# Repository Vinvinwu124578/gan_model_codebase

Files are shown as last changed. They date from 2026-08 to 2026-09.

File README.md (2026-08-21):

# TacTip GAN Coverage Board and CR3 Sampler

这个仓库保存用于 TacTip sim-to-real GAN 数据采集的完整硬件与自动采样流程：

- 四块可打印的高凸起几何覆盖板 STL；
- 与 150 mm M6 孔距配合的 TacTip 校准托座；
- Dobot CR3 自动规划、IK 预检、视觉接触检测及触觉图像采集脚本；
- 采样板/托座重新生成与装配预览工具。

仓库中的默认硬件是实际用于 CR3 调试的 **v4 deep-contact 版本**。每块板为
`170 x 170 mm`，四块组装后为 `340 x 340 mm`；每块板的四个 M6 孔中心距为
`150 x 150 mm`，板孔直径为 `6.0 mm`。

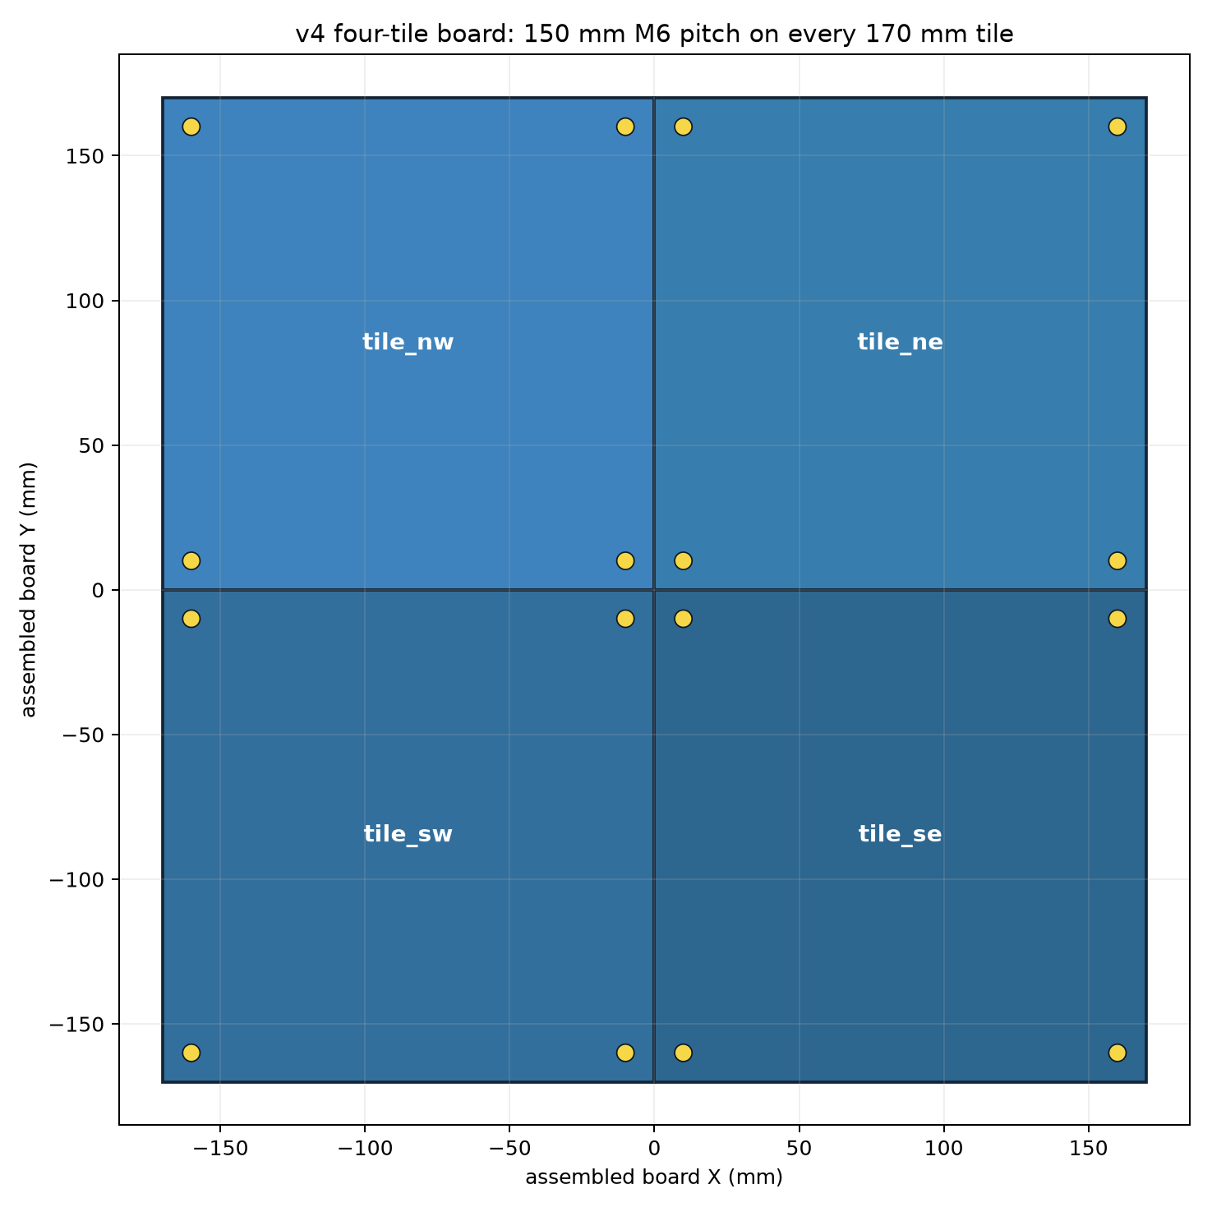
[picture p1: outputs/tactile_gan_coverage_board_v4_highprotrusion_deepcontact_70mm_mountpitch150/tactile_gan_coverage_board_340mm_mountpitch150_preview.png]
Four-tile mounting layout


## Repository layout

```text
tools/
  auto_cr3_v4_150mm_coverage_board_sampler.py   # 推荐入口
  auto_cr3_coverage_board_sampler.py            # 完整规划与采集实现
  preprocess_tactip_markers.py                  # 批量 Hough + 颜色二值化
  tactip_hough_chromatic.py                     # 批处理与在线采样共用算法
  tactip_runtime_preprocess.py                  # 自动采样在线预处理封装
  ...                                           # CR3、相机、预处理与硬件生成依赖

outputs/tactile_gan_coverage_board_v4_highprotrusion_deepcontact_70mm_mountpitch150/
  tactile_gan_coverage_board_340mm_tile_*.stl   # 四块打印板
  tactile_gan_coverage_board_340mm_manifest.json
  tactile_gan_coverage_board_340mm_sampling_sites.csv
  tactile_gan_coverage_board_340mm.urdf
  tactip_calibration_dock_lightweight_v1/       # 默认且经过实机流程使用的托座
  tactip_calibration_dock_verified_pitch_v2/    # 可选 150 mm 封闭孔夹持版

tactile_sim2real/pairing.py                     # 配对计划辅助模块
```

不会提交机器人专用的 fixture profile、Tool(2) TCP 或实物采样运行结果。每台机器、
每次重新安装托座后都必须重新示教。

## Installation

Python 3.10 或更高版本：

```bash
python3 -m venv .venv
source .venv/bin/activate
python -m pip install --upgrade pip
python -m pip install -r requirements.txt
```

macOS 还需要在“系统设置 -> 隐私与安全性 -> 相机”中允许 Terminal/Python 使用相机。
`tkinter` 由 Python 系统安装提供，不在 `requirements.txt` 中。

## TacTip image preprocessing

默认预处理已替换为 Hough 圆边界检测与蓝黄颜色过滤：

1. 灰度梯度只用于 Hough 圆周投票，不寻找最亮像素；
2. 对每个圆内部计算 `2B-G-R` 中位数，保留蓝灰 marker，排除金黄玻璃反光；
3. 使用当前图片实测的圆心和半径生成严格 `0/255` 二值图；
4. 原分辨率与 `256 x 256` 输出都必须保持 331 个独立连通域，否则拒绝该帧；
5. 原始相机照片永远保留，不会被预处理图覆盖。

处理单张图片：

```bash
.venv/bin/python tools/preprocess_tactip_markers.py \
  --input /absolute/path/to/tactip.png \
  --output-dir outputs/preprocessed_test
```

处理文件夹：

```bash
.venv/bin/python tools/preprocess_tactip_markers.py \
  --input /absolute/path/to/raw_images \
  --glob '*.png' \
  --output-dir outputs/preprocessed_batch
```

自动采样器默认启用同一套算法，标准模型输入保存在
`tactip_preprocessed/model_input_256/`。使用 `--no-tactip-preprocess` 可以只保存原图。
当前默认参数以 1280×960 实拍图为基准，圆间距、半径和 ROI padding 会随输入分辨率
自动缩放；颜色阈值保持在原始 8-bit BGR 色域中。

## Print and assemble

1. 打印 `tile_nw`、`tile_ne`、`tile_sw`、`tile_se` 四个 STL，触觉几何朝上。
2. 按 NW/NE、SW/SE 的顺序组装，不能单独旋转某一块。
3. 使用四角 `6.0 mm` M6 孔把每块板固定在同一平面上。
4. 默认托座安装在当前板块的 local `-Y` 边，并共用南侧两个 150 mm 间距的孔。
5. TacTip 刚性外壳落入圆形定位环，软触头朝下，电缆从外侧开槽离开。

默认托座及装配图位于：

```text
outputs/tactile_gan_coverage_board_v4_highprotrusion_deepcontact_70mm_mountpitch150/
  tactip_calibration_dock_lightweight_v1/
```

`verified_pitch_v2` 是更刚性的封闭孔替代版。更换托座版本后必须使用相应的 design
JSON，并重新示教 fixture profile；不能复用旧托座的 TCP。

## Safe workflow

以下命令都要在仓库根目录运行。示例使用 `tile_nw`、CR3 地址
`192.168.31.88`、Tool 2。

### 1. Teach the seated dock pose

先手动把 TacTip 完全落入托座，再执行：

```bash
.venv/bin/python tools/auto_cr3_v4_150mm_coverage_board_sampler.py \
  --tile tile_nw \
  --teach-dock-from-current \
  --robot-ip 192.168.31.88 \
  --tool 2
```

此步骤只读取当前位置，不发送运动指令。

### 2. Generate a 2,000-sample plan without moving CR3

```bash
.venv/bin/python tools/auto_cr3_v4_150mm_coverage_board_sampler.py \
  --tile tile_nw \
  --samples-per-tile 2000 \
  --dense-spatial-layout region_grid \
  --dense-region-anchor-count 25 \
  --min-post-contact-depth-mm 1 \
  --max-post-contact-depth-mm 10 \
  --output-dir outputs/plans/tile_nw_2000
```

输出包括 CSV、JSON 和可旋转 HTML 规划预览，不连接相机，也不移动机械臂。

### 3. Controller IK preflight without motion

机械臂已上电且 TacTip 仍在示教托座位置时：

```bash
.venv/bin/python tools/auto_cr3_v4_150mm_coverage_board_sampler.py \
  --tile tile_nw \
  --samples-per-tile 2000 \
  --dense-spatial-layout region_grid \
  --dense-region-anchor-count 25 \
  --min-post-contact-depth-mm 1 \
  --max-post-contact-depth-mm 10 \
  --ik-preflight-only \
  --robot-ip 192.168.31.88 \
  --tool 2
```

采样器会检查 `site_high`、approach、contact、最深压入及 retreat，并用候选点替换
不可达点；该模式不会发送 MovL。

### 4. Real collection

先只使用 `--max-samples 1 --first-contact-test` 做有人看护的 1 mm 首次接触测试。
确认坐标、方向、接触检测和回程都正确后，才运行完整批次：

```bash
.venv/bin/python tools/auto_cr3_v4_150mm_coverage_board_sampler.py \
  --tile tile_nw \
  --samples-per-tile 2000 \
  --dense-spatial-layout region_grid \
  --dense-region-anchor-count 25 \
  --min-post-contact-depth-mm 1 \
  --max-post-contact-depth-mm 10 \
  --camera-source 0 \
  --robot-ip 192.168.31.88 \
  --tool 2 \
  --speed 3 \
  --allow-depth-above-csv-limit \
  --return-to-dock \
  --execute \
  --yes-i-confirm-cr3-is-safe
```

`--allow-depth-above-csv-limit` 只能在已经物理验证板材、固定方式与 TacTip 能承受
1-10 mm 协议后使用。

## Safety

- 未同时提供 `--execute` 和 `--yes-i-confirm-cr3-is-safe` 时，脚本不会发送运动。
- 新装夹必须先生成预览，再执行 IK preflight，最后进行单点低压入测试。
- 自动 IK 只能检查运动学可达性，不能替代完整机械臂、线缆、夹具和环境碰撞检查。
- 接触失败默认安全回到高位并停止批次；不要在不检查机器人状态时盲目续跑。
- 急停、保护空间、速度限制和现场看护仍由操作者负责。

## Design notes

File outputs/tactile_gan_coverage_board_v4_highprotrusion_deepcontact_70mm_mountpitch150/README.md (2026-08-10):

# v4 70 mm Coverage Board: 150 mm M6 Pitch

This is a non-destructive mounting-hole variant of the original v4 deep-contact board. Each of the four 170 x 170 mm tiles keeps the same tactile geometry, STL-local frame, URDF frame and sampling CSV as v4. Only its four M6 clearance holes changed.

## Hole pattern

Every tile uses local hole centres `(-75,-75)`, `(-75,75)`, `(75,-75)`, `(75,75)` mm. The horizontal and vertical centre-to-centre pitch is therefore exactly `150 mm`. The nominal M6 hole diameter is `6.0 mm`.

The calibration dock for this variant attaches to one edge pair at local Y = -75 mm.

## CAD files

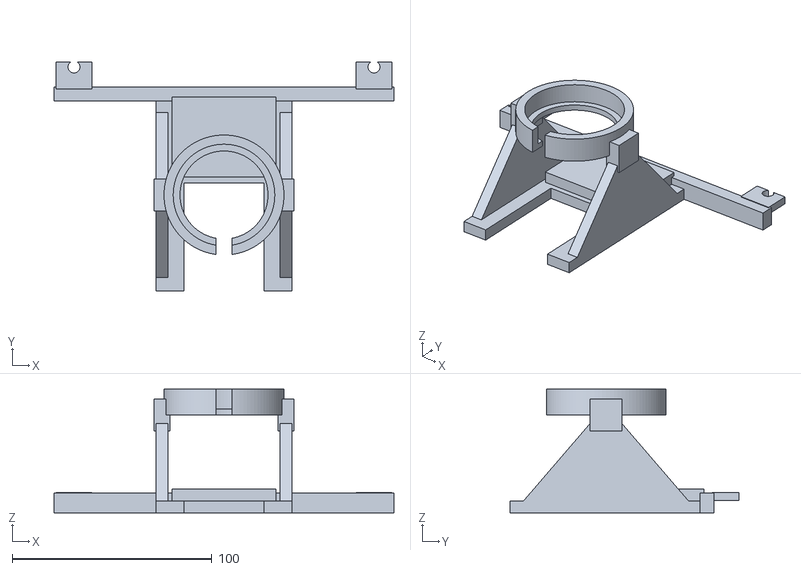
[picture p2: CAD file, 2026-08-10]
outputs/tactile_gan_coverage_board_v4_highprotrusion_deepcontact_70mm_mountpitch150/tactip_calibration_dock_lightweight_v1/v4_150mm_tactip_calibration_dock_lightweight.stl
170.0 x 114.5 x 62.0

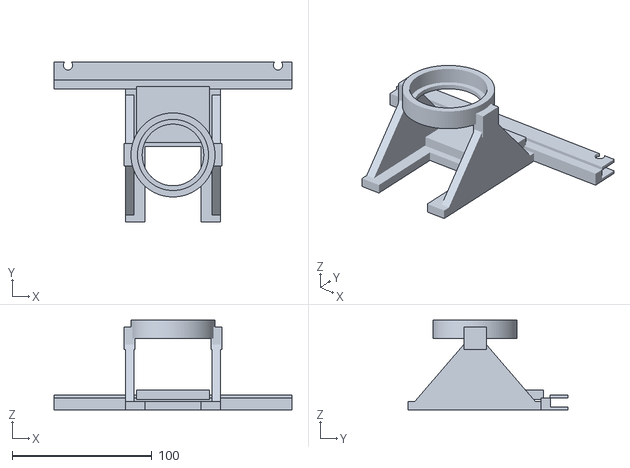
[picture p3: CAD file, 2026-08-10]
outputs/tactile_gan_coverage_board_v4_highprotrusion_deepcontact_70mm_mountpitch150/tactip_calibration_dock_verified_pitch_v2/v4_tactip_calibration_dock_v2_exact_150.stl
170.0 x 114.5 x 64.0

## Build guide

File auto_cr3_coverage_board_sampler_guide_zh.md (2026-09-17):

# `auto_cr3_coverage_board_sampler.py` 详细说明

> 源文件：`tools/auto_cr3_coverage_board_sampler.py`<br>
> 适用版本：2026-09-16 当前工作区版本（约 5,271 行）<br>
> 目标读者：需要理解、运行、调试或继续开发 CR3 + TacTip 覆盖板自动采样流程的研究人员

## 1. 这个脚本解决什么问题

这个脚本是四块 GAN 触觉覆盖板的真实机械臂采样入口。它把下面几件本来相互独立的事情串成一个受约束的流程：

1. 从固定 TacTip 托座建立真实 CR3 坐标系与板子 CAD 坐标系之间的刚体关系。
2. 根据板子 manifest、采样点 CSV 和解析几何生成触觉采样计划。
3. 把每个板上采样点换算成 CR3 基座坐标系中的 TCP 位姿。
4. 在运动前检查起始托座状态、Tool/User、IK、运动反馈和深度上限。
5. 在每个点建立新的无接触图像基线，再用 marker 光流寻找真实接触。
6. 从视觉接触点继续压入指定深度并保存原图、预处理图、TCP 和统计量。
7. 处理无接触、断点续采、整批 IK 筛选、回托以及受限恢复。
8. 输出可复核的 CSV、JSON、HTML 轨迹和图像报告。

它不是单纯的“读 CSV 后逐点 `MovL`”脚本。它同时承担了坐标配准器、采样规划器、视觉接触检测器、机器人安全门、数据记录器和恢复工具的职责。

## 2. 最重要的设计原则

### 2.1 托座是机械配准基准

脚本不在每次运行时重新拟合任意三维点。TacTip 放入具有机械键位的固定托座后，保存的 Tool(2) TCP 和托座设计文件共同确定板子坐标系。

对于带横档的托座，还会保存 TacTip 接触横档时的触觉图像。正式运行必须同时满足：

- 当前 Tool(2) TCP 与保存的托座 TCP 相符；
- 当前触觉图像与保存的横档接触图像相符。

因此，“TCP 在附近但 TacTip 没真正落到底”不会被当成有效归位。

### 2.2 CAD 高度只负责给出名义位置

模型提供每个点的名义表面高度，但最终是否接触由实时触觉图像决定。实际流程是：

```text
CAD 名义表面
    -> 从上方逐步接近
    -> marker 位移达到动态阈值
    -> 得到视觉接触点
    -> 再压入该样本要求的 1-10 mm
```

这样可以吸收打印误差、装配高度误差和局部曲面高度差，但搜索仍受硬深度上限约束。

### 2.3 每个真实 `MovL` 前都做即时 IK

默认不会在 2,000 点运行前等待整批 IK 扫描，但 `move_and_verify()` 会在每个真实 `MovL` 前读取当前关节角，并用相同 near-joint 分支调用控制器 `InverseSolution`。没有解时不会发送该次 `MovL`。

`--preflight-all-routes` 是额外的整批筛选，不是即时 IK 的替代品。

### 2.4 失败时不猜测机器人位置

如果 `GetPose`/`GetAngle` 反馈无效、运动误差超限或异常发生在未知阶段，脚本记录错误并停止，不会擅自发送恢复动作。只有起点落在明确限定的几何包络中时，专用恢复模式才允许移动。

## 3. 总体架构

```mermaid
flowchart TD
    A[parse_args 参数解析与静态安全校验] --> B[load_dock_design / load_board_data]
    B --> C{运行模式}
    C -->|托座教学| D[teach_dock_profile / teach_rest_stop_height_profile]
    C -->|仅相机| E[run_capture_camera_only]
    C -->|恢复| F[run_reseat_dock / run_recover_*]
    C -->|计划或采集| G[filter_tile_rows]
    G --> H[build_samples / build_dense_samples]
    H --> I[fixture_from_profile]
    I --> J[make_route]
    J --> K[写 CSV/JSON/HTML 预览]
    K --> L{execute?}
    L -->|否| M[离线计划结束]
    L -->|是| N[run_collection]
    N --> O[检查托座 TCP 与横档触觉图]
    O --> P[可选整批 IK 筛选]
    P --> Q[移动至 site approach]
    Q --> R[search_visual_contact]
    R --> S[最终压入并拍摄]
    S --> T[抬升到 site-high]
    T --> U{还有样本?}
    U -->|是| Q
    U -->|否| V[回托或停在最后 site-high]
    V --> W[collection.json / samples.csv / HTML 报告]
```

## 4. 外部模块边界

主脚本负责组织流程，但以下能力来自同仓库其他模块：

| 模块 | 主脚本使用的能力 |
|---|---|
| `auto_cr3_gelsight_pair_sampler.py` | `GelSightCapture`：打开相机、后台读取带时间戳的新帧 |
| `auto_cr3_visual_contact_search.py` | 多帧中值拍摄、marker 光流统计、位姿误差、`move_and_verify()`、动态图像阈值 |
| `design_tactile_gan_coverage_board_modular.py` | 根据区域 profile、stimulus 和局部 X/Y 解析计算曲面 Z 高度 |
| `live_cr3_gelsight_sampler.py` | `DobotCR3LiveClient`、相机 source 解析、CR3 TCP/IP 命令 |
| `runtime_board_height_datum.py` | 运行时板高基准的绑定、质量检查、生成与加载 |
| `tactip_runtime_preprocess.py` | 331-pin Hough/色彩筛选、原分辨率 marker 图、256x256 模型输入 |

需要特别区分：本文件决定“什么时候拍、什么时候移动、拍完如何判断”；marker 的具体检测和 LK 光流计算在外部模块中实现。

## 5. 输入文件

### 5.1 板子目录 `--board-dir`

目录中必须恰好有一个 `*_manifest.json`。manifest 至少需要描述：

- 四块 tile 的 `tile_id`、中心坐标和 STL；
- 每块 tile 包含哪些 `region_id`；
- 采样 CSV 的相对路径；
- `height_profile`；
- 区域中心、TacTip 名义直径和安全特征区尺寸。

采样 CSV 至少被脚本使用的列包括：

- `site_id`、`region_id`、`category`、`stimulus`；
- `board_x_mm`、`board_y_mm`、`expected_surface_z_mm`；
- `sampling_jitter_radius_mm`；
- `recommended_depth_min_mm`、`recommended_depth_max_mm`。

### 5.2 托座设计 `--dock-design`

JSON 必须属于支持的 schema，并包含：

- `tactip_reference.nominal_seated_tool_tcp_local_mm`；
- 对应的 `tool` 编号；
- 可选 `rest_pose_stop`：横档接触中心和顶面高度；
- 可选 `reference_pad`；
- 可选 STL 路径，仅用于预览。

`geometry_preview_only` 文件可以做离线可视化，但不能授权教学、标高或真实运动。

### 5.3 实物配准 profile `--fixture-profile`

由本脚本教学模式生成，包含：

- 保存的真实 `dock_tcp`；
- Tool、User、tile；
- 托座设计文件 SHA-256；
- 固定 `board_yaw_deg`；
- 横档高度标定和触觉参考图（v3 profile）。

加载时会核对 tile、Tool、User 和托座设计哈希，避免把另一次装夹的 profile 误用于当前实物。

## 6. 坐标系与数学关系

### 6.1 三个核心坐标系

| 坐标系 | 含义 |
|---|---|
| tile local | 板子 CAD 坐标；采样点、区域中心和安全高度都在这里定义 |
| CR3 base | 机器人 `GetPose`/`MovL` 使用的基座坐标 |
| Tool local | Tool(2) 的末端坐标；Tool `+Z` 被定义为真实压入方向 |

保存 profile 时采用以下方向约定：

```text
tile +X = 托座位姿下 Tool +X
tile +Y = 托座位姿下 Tool -Y
tile +Z = 托座位姿下 Tool -Z（物理向上）
Tool +Z = 物理压入方向（向板面）
```

### 6.2 `FixtureTransform` 的变换

固定轴适配矩阵为：

```text
A = diag(1, -1, -1)
```

如果保存的托座旋转矩阵是 `R_dock`，固定板面偏航角是 `R_yaw`，则：

```text
R_tile_to_base = R_dock * A * R_yaw
```

tile-local 点 `p_local` 转为 CR3 base 点：

```text
p_base = p_dock_base + R_tile_to_base * (p_local - p_dock_local)
```

反变换由 `base_to_tile_local()` 完成：

```text
p_local = p_dock_local + R_tile_to_base^T * (p_base - p_dock_base)
```

### 6.3 倾角与压入轴

`tilt_x_deg` 和 `tilt_y_deg` 分别绕已经映射到 base 坐标中的 tile X、Y 轴旋转。最终方向为：

```text
R = R_tilt_y * R_tilt_x * R_dock
press_axis_base = R * [0, 0, 1]^T
```

因此压入不是简单修改 CR3 的 Z 值，而是沿当前 Tool `+Z` 在 base 坐标中的单位向量运动。倾斜采样时 X、Y、Z 都可能同时变化。

### 6.4 Euler 角的数值连续性

同一个旋转可以写成 `+178°` 或 `-182°`。`FixtureTransform.pose()` 会把新 Euler 角包裹到靠近托座保存角度的等价值，便于检查计划，也减少控制器看到不必要的 360° 数值跳变。

## 7. 核心数据结构

### 7.1 `FixtureTransform`

冻结 dataclass，保存一次装夹的刚体映射。

| 字段/方法 | 作用 |
|---|---|
| `dock_tcp` | 实测托座 Tool TCP，6 维 |
| `dock_tcp_local_mm` | 同一基准在 CAD/tile local 中的 3D 坐标 |
| `tile_to_base` | tile local 到 CR3 base 的 3x3 旋转矩阵 |
| `dock_rotation` | 托座 TCP 本身的旋转矩阵 |
| `board_yaw_deg` | 装夹中固定的板面偏航角 |
| `position()` | 只变换位置 |
| `orientation()` | 生成带 X/Y 倾角的末端旋转 |
| `pose()` | 生成完整 X/Y/Z/Rx/Ry/Rz |
| `press_axis()` | 得到 base 坐标中的真实压入轴 |
| `local_vector()` | 把 base 中的位移向量旋回 tile local |

### 7.2 `BoardSample`

每个计划样本的不可变记录。关键字段分为四组：

| 组 | 字段 |
|---|---|
| 身份 | `index`、`sample_id`、`tile_id`、`source_seed_site_id`、`region_id` |
| 物理类别 | `category`、`stimulus`、`replicate` |
| 接触位置 | `local_contact_mm`、`expected_surface_z_mm`、`jitter_x_mm`、`jitter_y_mm` |
| 接触条件 | `post_contact_depth_mm`、`tilt_x_deg`、`tilt_y_deg` |

`local_contact_mm` 是 tile 中的名义零接触点；`post_contact_depth_mm` 是视觉找到真实接触后继续压入的量，两者不能混为一谈。

## 8. 运行模式与分派顺序

`run()` 按以下优先级分派。前面的模式命中后不会继续执行后面的普通采样逻辑。

| 顺序 | 模式 | 是否连接 CR3 | 是否运动 |
|---:|---|---:|---:|
| 1 | `--capture-camera-only` | 否 | 否 |
| 2 | `--calibrate-height-from-rest-stop` | 是 | 否 |
| 3 | `--teach-dock-from-current` | 是 | 否 |
| 4 | `--recover-low-pose-to-dock` | 是 | 取决于 `--execute` |
| 5 | `--calibrate-runtime-height` | 是 | 是 |
| 6 | 普通规划、预览、预检或采集 | 视后续参数而定 | 视后续参数而定 |

普通规划完成后又按以下优先级执行：

1. `--reseat-dock-only`
2. `--recover-reference-to-dock`
3. `--verify-dock-tactile-reference-only`
4. `--ik-preflight-only`
5. 没有 `--execute`：仅输出计划
6. 有 `--execute`：进入 `run_collection()`

## 9. 一次正式采集的完整时序

### 9.1 离线阶段

1. 解析参数并拒绝不兼容组合。
2. 加载托座设计、板子 manifest 和采样 CSV。
3. 按 tile、region、site 筛选 CSV。
4. 生成普通或精确数量的 dense 样本。
5. 应用零倾角、首点测试、断点续采等变换。
6. 加载 fixture profile，并检查哈希与 Tool/User。
7. 生成每个样本的名义 contact、approach、site-high 和最深允许点。
8. 写出计划 CSV/JSON 和交互式 HTML；此阶段不会连接机械臂。

### 9.2 连接设备后的起始安全门

1. 打开相机并创建预处理器。
2. 连接 CR3，设置 User/Tool，要求机器人可运动且空闲。
3. 读取当前关节和 TCP。
4. `dock_alignment_decision()` 把状态分为：
   - `already_seated`：在托座容差内；
   - `aligned_above_dock`：XY/姿态几乎完全对齐，只在托座上方 0.1-5 mm；
   - `unsafe_start_pose`：其余状态。
5. 第二种状态默认允许以不高于 1% 的速度纯竖直回落到保存 TCP；第三种状态拒绝移动。
6. 对有横档的托座，再拍一张实时触觉图，与保存参考比较 marker 位移、纹理相关性和归一化 MAE。

### 9.3 离开托座与整批 IK 策略

默认不接触额外 reference pad，而是：

```text
seated dock -> dock_exit
```

然后确认实际 TCP 已到 `dock_exit`。如果启用 `--preflight-all-routes`，此时检查候选池并用可达备用点替换不可达点；默认则保留原计划，只在每次真实运动前做即时 IK。

### 9.4 单样本运动与接触

普通非连续模式的进场路线：

```text
dock_exit -> dock_high -> site_high -> approach
```

连续模式除首点外的进场路线：

```text
previous site_high -> next site_high -> approach
```

到 approach 后：

1. 拍无接触 baseline。
2. 原地拍多组 noise probe，计算当前点自己的阈值。
3. 沿 `press_axis_base` 每次最多移动 0.5 mm。
4. 每步拍新图并计算 marker 位移 mean 和 P95。
5. 两项均超过阈值才算 hit。
6. 在同一 TCP 再拍，达到 `consecutive_hits` 才确认接触。
7. 沿同一压入轴继续移动 `post_contact_depth_mm`。
8. 拍最终 capture，保存图像与实际 TCP。
9. 抬升回 site-high。

### 9.5 批次结束

默认通过 dock-high、dock-exit 回到保存的托座 TCP。也可以用 `--leave-at-site-high` 留在最后一个 site-high，但这只适合诊断。

## 10. 样本规划模块

### 10.1 CSV 筛选

`filter_tile_rows()` 先按当前 tile 的 `region_ids` 过滤，再应用可重复的 `--region` 和 `--site`。不存在的 region/site 立即报错，不会静默忽略。

### 10.2 quick / standard / dense profile

没有 `--samples-per-tile` 时使用 profile：

| profile | seed 选择 | 每个 seed 重复数 |
|---|---|---:|
| `quick` | 只取编号 1、5、9 | 1 |
| `standard` | 全部 | 2 |
| `dense` | 全部 | 4 |

倾角从 `TILTS_BY_CATEGORY` 中按类别轮换。flat/curvature/multi-touch 最大约 3°，edge X 方向可到 4°，small-feature 最大约 2°。

### 10.3 精确数量 dense 计划

提供 `--samples-per-tile N` 后，`build_dense_samples()` 保证最终恰好生成 N 个样本：

1. 在选择到的 region 间尽量平均分配数量。
2. 默认 `region_grid` 在每个区域建立正方形锚点阵列。
3. 锚点窗口会扣除 TacTip 半径，避免圆形触头跨入相邻单元。
4. 每个格点加入不超过单元尺寸 10% 的确定性低差异扰动。
5. 用互质 stride 遍历锚点，先覆盖全部位置再重复。
6. 每个实际 X/Y 绑定最近的 CSV seed，用它的类别、stimulus 和安全压深区间。
7. 用解析曲面函数重新计算该 X/Y 的表面 Z，而不是复制最近 seed 的 Z。
8. 压深和倾角都由带 seed 的低差异序列产生，因此可复现。

如果明确指定 `--site`，默认的 `region_grid` 会自动变成围绕该 seed 的 `seed_jitter`，用于局部重复实验。

### 10.4 压深分布

默认全局要求是 1-10 mm，但 `--respect-csv-depth-limits` 默认开启。每个样本实际允许范围为：

```text
lower = max(全局最小值, CSV 推荐最小值)
upper = min(全局最大值, CSV 推荐最大值)
```

没有交集会在规划阶段报错。区间内使用 base-5 低差异序列，而非普通伪随机数。

使用 `--ignore-csv-depth-limits` 时，真实执行如果存在超出 CSV 上限的样本，还必须显式增加 `--allow-depth-above-csv-limit`。

### 10.5 IK 备用候选池

只在整批 IK 预检时需要。候选数为：

```text
ceil(请求样本数 * ik_candidate_multiplier)
```

默认倍数是 2。备用点继续同一确定性 dense 序列，因此替换不可达点时不会跳出已知安全区域，也不会破坏每个 region 的目标数量。

## 11. 路线规划模块

### 11.1 `make_route()` 生成的关键位姿

| 位姿 | 含义 |
|---|---|
| `contact_tcp` | CAD/高度校正后的名义零接触位姿 |
| `approach_tcp` | 沿压入轴反方向退 `approach_clearance_mm` |
| `site_high_tcp` | 相同 X/Y、配置的 tile-local 安全高度 |
| `dock_exit` | 从托座基准沿 tile +Z 纯竖直抬升 |
| `dock_high` | 托座 X/Y 上方的公共安全高度 |

板高 correction 只作用于板面 contact/approach；托座和公共安全高度不跟着改变。对 site-high 的 correction 还会去掉任何会降低安全面的法向分量。

### 11.2 最深允许 TCP

对样本压深 `d` 和接触搜索余量 `m`：

```text
maximum_below_nominal = min(全局硬上限, d + m)
```

视觉找接触本身最多走到：

```text
max_contact_depth_from_approach
    = approach_clearance + maximum_below_nominal - d
```

找到接触后再压入 `d`。因此最终 capture 不会深于名义面下 `maximum_below_nominal`。这里特意为最终压入预留了空间，不能把“接触搜索距离”和“压入深度”直接相加两次。

### 11.3 连续采样模式

`--continuous-board-transit` 不会在每个点后回托：

```text
contact -> current site_high -> next site_high -> next approach
```

所有横向运动仍在共同的 `safe_height_mm` 完成。它显著提高效率，但不会取消每次 `MovL` 的即时 IK 和反馈检查。

## 12. 视觉接触检测模块

### 12.1 图像输入

默认相机设置为 1280x960、30 fps。每次“拍一张”不是取单帧，而是读取若干质量合格的新帧后做逐像素中值，降低闪烁和偶发模糊。

严格预处理要求每张被接受图像独立检测到配置数量的 marker（默认 331）。检测失败时只重拍新图，不会从上一张图补点。

### 12.2 每个采样点都有独立 baseline

`prepare_site_baseline()` 在 approach 位姿执行：

1. 用 `baseline_frames` 拍 baseline。
2. 原地再拍 `noise_probes` 组图。
3. 每组都与 baseline 计算去除整体相机运动后的局部 marker 位移。
4. 分别得到 mean 和 P95 的噪声序列。

动态阈值公式为：

```text
threshold = max(
    人工下限,
    noise_median + noise_multiplier * max(1.4826 * MAD, 0.05)
)
```

默认人工下限：mean 0.10 px，P95 0.45 px。

### 12.3 命中规则

某一步只有同时满足以下条件才是 contact evidence：

```text
marker_motion.mean >= threshold.mean
AND
marker_motion.p95 >= threshold.p95
```

之后保持同一位姿再次拍摄。默认至少连续命中两次；高度测量和运行时标高会强制至少三次。

### 12.4 为什么在同一位姿确认

确认帧不会继续向下移动。这样首个命中 TCP 仍对应同一个机械位置，也不会因为“为了确认又压了一步”而消耗最后的深度预算。

### 12.5 高度测量的 bracket refinement

普通数据采集只需要稳定找到接触。`--height-measurement` 还要估计接触阈值所在的窄区间：

1. 先记录最后一个 no-contact TCP 和第一个 contact TCP。
2. 回到 no-contact 端确认已经释放。
3. 在已探索区间内按最多 0.02 mm 步长重新前进。
4. 只接受宽度不超过 0.04 mm 的正 bracket。

它测量的是“图像检测阈值接触”，不是力传感器定义的严格零力接触。

运行时全板高度标定故意使用已经稳定确认的 0.5 mm 粗 bracket，不在已形变、可能有反光的图像中继续多次细探。

### 12.6 中间图像的保留策略

默认只保留最终 capture。baseline、noise、search 和 confirm 图在统计用完后删除，以免 2,000 点实验被中间帧占满磁盘。

使用 `--save-search-frames` 可保留全部诊断图；高度测量会自动开启它。

## 13. IK 与运动反馈模块

### 13.1 即时运动保护

每次 `move_and_verify()` 的顺序是：

1. 验证目标是 6 个有限数值。
2. 读取 `RobotMode`，只接受 enabled and idle 状态 5。
3. 读取当前关节角作为 near-joint 分支提示。
4. 调用控制器 `InverseSolution`。
5. 只有 IK 成功才发送 `MovL`。
6. 运动结束后读取真实 `GetAngle` 和 `GetPose`。
7. 再次检查 RobotMode。
8. 对比目标与真实 TCP，默认限值 0.75 mm / 1.5°。

如果真实反馈缺失，不能把命令目标冒充成测量结果；脚本抛错并禁止自动恢复。

### 13.2 整批 IK 预检

`--preflight-all-routes` 对每个候选检查五个分支连续的目标：

1. site-high
2. approach
3. planned contact
4. deepest capture limit
5. 从最深点分支返回 site-high

每一个 IK 解都会成为下一个目标的 near-joint 提示，因此检查的是一条连续关节分支，而不只是每个 TCP 是否存在任意解。

无 near-hint 的 IK 查询仅在 `--ik-diagnose-failures` 下用于诊断“真不可达”还是“当前分支不可达”；它即使成功也不会授权候选点。

### 13.3 精确缓存

整批过滤可缓存成功 IK，key 包含完整目标 pose、完整 near-joints、User 和 Tool，不做数值舍入。这个缓存只存在于无运动筛选阶段；真实 `MovL` 前仍重新查询控制器。

## 14. 托座、高度与配准模块

### 14.1 传统托座教学

`--teach-dock-from-current` 对无横档的旧托座只读取当前 TCP，不移动，并写 v1 profile。

### 14.2 横档托座标定

带 `rest_pose_stop` 的托座无论使用 `--teach-dock-from-current` 还是 `--calibrate-height-from-rest-stop`，都会进入强化流程：

1. 验证横档接触点与 nominal seated TCP 在 CAD 中一致。
2. 间隔 0.25 秒读取两次 TCP，要求机械臂稳定。
3. 拍主参考图。
4. 静置后拍重复图。
5. 从两图的 marker motion 和纹理差异建立接受带。
6. 写入 v3 fixture profile 和独立参考图目录。

### 14.3 正式运行的横档触觉核验

实时图与参考图比较：

- 局部 marker motion mean；
- 局部 marker motion P95；
- 鲁棒亮度归一化后的纹理相关系数；
- 归一化纹理 MAE。

marker motion 和 TCP 是主要门槛；纹理用于阻止明显错图，但阈值较宽，以容忍 LED/玻璃反光随时间漂移。

### 14.4 自动短距离回落

当前 TCP 只有同时满足以下条件才允许自动回落：

- 在保存托座上方 0.1-5.0 mm；
- tile-local 横向误差不超过 0.25 mm；
- 姿态误差不超过 0.25°；
- 不是低于托座，也不是任意远处。

回落速度被限制为 1%。回落后仍需重新读 TCP，并完成触觉横档核验。

### 14.5 运行时板高标定

`--calibrate-runtime-height` 不使用曲边或凸起估计全局高度。它只选择一个已知 `flat_reference` 平面的四个外侧点，每点重复三次，共 12 个零倾角、零额外压入的视觉接触。

所有质量门通过后才发布 datum；失败只留下 candidate/report，不会覆盖先前已接受的 datum。

使用 datum 时，脚本给每个 region 使用记录的 tile-Z offset 作为名义高度修正，但每次 capture 仍必须实时找视觉接触。

## 15. 无接触、续采与恢复

### 15.1 默认无接触行为

找不到稳定接触时，脚本先沿已知路径退到 site-high。默认停止整批并回托，状态写为 `stopped_after_no_contact`。

`--continue-on-no-contact` 会把该样本记为 no-contact，并只在确认已回到 site-high 后继续下一个点。

### 15.2 安全断点续采

`--resume-from-run` 不是简单跳过前 N 行。它要求：

- 原 collection 状态是 `stopped_after_no_contact`；
- 原运行最终已回到 seated dock TCP；
- board manifest、dock design、fixture profile 哈希完全一致；
- 当前命令重新生成的完整样本序列与旧计划逐字段一致；
- 已尝试记录是该计划的非空严格前缀。

满足后才从第一个未尝试样本继续，并创建新输出目录，不修改旧运行。

### 15.3 专用恢复模式

| 模式 | 允许的起点 | 路线 |
|---|---|---|
| `--reseat-dock-only` | seated、dock-exit 或 dock-high 附近 | 回 dock-exit 后落座，或直接落座 |
| `--recover-reference-to-dock` | reference pad 接近轴线上 | reference-high -> dock-high -> dock-exit -> seated |
| `--recover-low-pose-to-dock` | 与 fixture 对齐、局部 Z 合法、距托座 XY 不超过 160 mm | 先只抬局部 Z 到 safe-height，再横移回托 |

低位恢复默认只做实时读取和 IK 预检；加入 `--execute --yes-i-confirm-cr3-is-safe` 才会运动。

## 16. 命令行参数分组说明

### 16.1 文件、tile 与样本选择

| 参数 | 默认/作用 |
|---|---|
| `--board-dir` | v4 高凸起覆盖板目录 |
| `--tile` | 必填，`tile_nw/ne/sw/se` |
| `--dock-design` | 默认 raised15mm camera-style rest-stop 设计 JSON |
| `--fixture-profile` | 默认使用托座目录下当前 tile 的 profile |
| `--output-dir` | 不给时创建带时间戳目录 |
| `--resume-from-run` | 验证后续采旧计划未尝试后缀 |
| `--profile` | `quick/standard/dense`，默认 standard |
| `--samples-per-tile` | 精确 dense 数量，例如 2000 |
| `--region` / `--site` | 可重复筛选 |
| `--max-samples` | profile 展开后的上限 |
| `--seed` | 默认 1729，用于可复现低差异扰动 |

### 16.2 dense 空间参数

| 参数 | 作用 |
|---|---|
| `--dense-spatial-layout` | `region_grid` 或 `seed_jitter` |
| `--dense-region-anchor-count` | 默认 25，必须是至少 4 的平方数 |
| `--dense-region-half-span-mm` | 手动缩小区域锚点窗口，不能超过自动安全值 |

### 16.3 标定与诊断模式

| 参数 | 作用 |
|---|---|
| `--teach-dock-from-current` | 从当前位置保存托座 TCP；横档托座自动走强化标定 |
| `--calibrate-height-from-rest-stop` | 保存横档 TCP 和触觉参考，无运动 |
| `--calibrate-runtime-height` | 用 12 次 flat-reference 接触生成板高 datum |
| `--verify-dock-tactile-reference-only` | 只核验 TCP+横档图，不运动 |
| `--capture-camera-only` | 用正式拍摄/预处理链保存一张图，不连 CR3 |
| `--height-measurement` | 单点细 bracket 高度测量 |
| `--height-calibration` | 加载外部多点高度标定 |
| `--runtime-height-datum` | 加载本脚本生成的运行时高度 datum |
| `--board-yaw-deg` | 仅教学时写入固定平面旋转 |

### 16.4 CR3 与相机

| 参数 | 默认 |
|---|---:|
| `--robot-ip` | `192.168.31.88` |
| `--dashboard-port` / `--move-port` | 29999 / 30003 |
| `--user` / `--tool` | 0 / 2 |
| `--speed` | 3%，合法范围 1-5% |
| `--camera-source` | `0` |
| `--width` / `--height` | 1280 / 960 |
| `--fps` | 30 |
| `--settle-sec` | 0.25 s |

### 16.5 接触与压深

| 参数 | 默认/约束 |
|---|---|
| `--step-mm` | 0.5 mm，最大 0.5 mm |
| `--min-post-contact-depth-mm` | 1 mm，不能更小 |
| `--max-post-contact-depth-mm` | 10 mm，不能更大 |
| `--approach-clearance-mm` | 25 mm |
| `--safe-height-mm` | tile-local 100 mm |
| `--dock-exit-lift-mm` | 65 mm |
| `--contact-search-margin-mm` | 1 mm；普通最多 4 mm |
| `--max-extra-below-planned-contact-mm` | 自动覆盖“最大压深+搜索余量”，绝对上限 12 mm |
| `--allow-deep-contact-localization` | 只允许一个 first-contact-test 把搜索余量放宽到 10 mm |
| `--respect-csv-depth-limits` | 默认开启 |
| `--ignore-csv-depth-limits` | 改用全局压深范围 |
| `--allow-depth-above-csv-limit` | 对超 CSV 深度的真实执行显式确认 |

### 16.6 视觉检测

| 参数 | 默认 |
|---|---:|
| `--baseline-frames` | 9 |
| `--noise-probes` | 3 |
| `--probe-frames` | 3 |
| `--capture-frames` | 9 |
| `--consecutive-hits` | 2 |
| `--noise-multiplier` | 3.0 |
| `--min-contact-mean` | 0.10 px |
| `--min-contact-p95` | 0.45 px |
| `--save-search-frames` | 默认关闭 |

### 16.7 marker 预处理参数

这些参数由 `tactip_runtime_preprocess.py` 注入：

| 参数 | 默认/作用 |
|---|---|
| `--tactip-preprocess-output-size` | 256 |
| `--tactip-preprocess-expected-markers` | 331，接受图必须达到精确数量 |
| `--tactip-preprocess-hough-vote-threshold` | 13.0，附近阈值会自动尝试 |
| `--tactip-preprocess-blue-yellow-threshold` | 20.0，用颜色分数排除黄/橙反光圆 |
| `--tactip-preprocess-render-radius-scale` | 0.90，控制二值 marker 绘制半径 |
| `--no-tactip-preprocess` | 只允许非正式离线/恢复场景；正式视觉接触禁止 |

### 16.8 IK、路线与结束策略

| 参数 | 作用 |
|---|---|
| `--disable-ik-preflight` | 连每次 `MovL` 前的即时 IK 也关闭，不建议正式实验使用 |
| `--preflight-all-routes` | 真实执行前扫描整个候选池 |
| `--ik-preflight-only` | 只连接控制器查整批 IK，不运动 |
| `--ik-candidate-multiplier` | 默认 2，范围 1-5 |
| `--ik-diagnose-failures` | IK 分支失败后额外查询无提示解，只做诊断 |
| `--continuous-board-transit` | 样本间在 site-high 直接移动 |
| `--continue-on-no-contact` | 无接触退高后继续 |
| `--return-to-dock` | 默认批末回托 |
| `--leave-at-site-high` | 批末留在最后安全高位 |

### 16.9 真机授权

只有同时给出下面两个参数，普通采集或恢复运动才会发送：

```text
--execute --yes-i-confirm-cr3-is-safe
```

参数名本身不是碰撞检测器；它只是要求操作员显式确认。实际保护还依赖正确的实物摆放、Tool(2)、fixture profile、安全高度和可见工作区。

## 17. 全部函数与功能模块索引

以下按源码顺序列出本文件的每个顶层函数。行号对应本文适用版本，后续修改可能漂移。

### 17.1 参数、文件和 profile（约 180-1371 行）

| 函数 | 职责、返回值与重要副作用 |
|---|---|
| `parse_args()` | 定义所有 CLI；规范化路径；自动调整高度模式参数；检查数值范围和不兼容组合。返回 `argparse.Namespace`，不连接硬件。 |
| `sha256_file(path)` | 以 1 MiB 分块计算文件 SHA-256，用于绑定板子、托座、profile 和续采来源。 |
| `read_json(path)` | 读取并要求根对象为 JSON object；数组根节点会报错。 |
| `write_json(path, payload)` | 创建父目录并以缩进 JSON 写盘。采集过程中被频繁调用，形成可恢复进度记录。 |
| `load_board_data(args)` | 要求板目录恰有一个 manifest，查找当前 tile，读取 sampling CSV。返回 `(manifest, tile, rows)`。 |
| `load_dock_design(args)` | 校验 dock schema、真实/预览属性、nominal TCP 和 Tool 编号。 |
| `rest_stop_contract(dock_design)` | 验证横档接触中心、横档顶面 Z 和 nominal seated TCP 三者一致；返回横档配置。 |
| `fixture_from_profile(profile, dock_design, args)` | 核对 schema/tile/User/Tool/哈希/横档记录，构造 `FixtureTransform`。不重新估计 yaw。 |
| `dock_alignment_decision(fixture, current_pose, args)` | 把当前 TCP 分类为已落座、仅在上方可自动回落或不安全起点；不运动。 |
| `read_stable_rest_stop_pose(robot, args)` | 间隔 0.25 s 读两次状态，检查静止性，返回第二个 TCP 和完整稳定性记录。 |
| `add_model_roi_path(record)` | 给 capture 记录补上共享预处理器 `model_roi` 的相对路径。 |
| `tactile_texture_similarity(reference, candidate)` | 在共同 ROI 内做 median/MAD 亮度归一化，输出相关系数、归一化 MAE 和共享像素数。 |
| `rest_stop_acceptance_from_repeat(repeat_record)` | 从静止重复拍摄建立 marker motion 接受上限，同时使用较宽的纹理防错阈值。 |
| `load_rest_stop_reference_feature(profile)` | 解析参考根目录和 gray/ROI 文件，检查存在后加载 `ImageFeature`。 |
| `verify_rest_stop_tactile_reference(...)` | 拍实时横档图并与 profile 参考比较；返回 passed/failed 记录，不直接抛出 mismatch。调用者决定是否阻止离托。 |
| `teach_rest_stop_height_profile(args, dock_design)` | 连接 CR3 和相机但不发运动；读稳定 TCP、拍两组横档图并写 v3 profile。 |
| `teach_dock_profile(args, dock_design)` | 旧托座写 v1 profile；带横档托座自动转调强化标定函数。 |

### 17.2 样本生成与统计（约 1372-2127 行）

| 函数 | 职责、返回值与重要副作用 |
|---|---|
| `filter_tile_rows(tile, rows, args)` | 按 tile/region/site 过滤并排序 CSV；空结果或不存在的过滤值报错。 |
| `profile_replicates(name)` | 把 quick/standard/dense 映射为 seed 子集和重复数。 |
| `seed_number(site_id)` | 从形如 `R07_S05` 的 ID 解析末尾 seed 数字。 |
| `sampling_label(args)` | 生成报告目录标签，例如 `2000-sample-dense`。 |
| `radical_inverse(index, base)` | 计算 Van der Corput 坐标，是 Halton/低差异序列基础。 |
| `low_discrepancy_fraction(index, base, seed, stream)` | 对低差异值做确定性 Cranley-Patterson 平移，让不同区域/seed 不共享完全相同模式。 |
| `planned_depth_bounds(args)` | 返回全局要求的最终压深上下限。 |
| `depth_bounds_for_seed(row, args)` | 求全局压深与该 CSV seed 推荐范围的交集。 |
| `uniformly_distributed_depth(...)` | 在允许区间中按低差异序列选一个可复现压深。 |
| `evenly_allocate(total, labels)` | 把整数总量尽量均匀分配给多个 region。 |
| `dense_region_grid_half_span_mm(manifest, args)` | 用安全特征区半宽减 TacTip 半径得到中心点最大安全半跨度，并验证人工值。 |
| `effective_dense_spatial_layout(args)` | 如果用户明确选择 site，把默认 region-grid 转为局部 seed-jitter。 |
| `dense_region_grid_offsets(...)` | 生成带小幅确定性扰动的平方锚点格。 |
| `coprime_stride(count)` | 选择与锚点数互质的遍历步长，重复前访问全部锚点。 |
| `closest_seed_row(rows, board_xy)` | 为任意 dense X/Y 找最近 CSV seed，继承元数据和安全压深。 |
| `dense_tilt(category, index, seed, stream)` | 在类别验证过的倾角方向上用低差异幅值产生倾角。 |
| `build_dense_samples(...)` | 生成精确数量、跨区域平衡、解析曲面高度、可复现的 dense `BoardSample` 列表。 |
| `build_samples(...)` | 没有精确数量时按 profile 展开 CSV；有精确数量时转调 dense 生成器。 |
| `resume_unattempted_samples(...)` | 验证旧计划和 collection 是当前计划的严格前缀，返回未尝试后缀，并把续采元数据挂到 args。 |
| `build_runtime_height_calibration_samples(...)` | 从单一 broad flat-reference 平面选四角，每点三次，生成 12 个零倾角零压入样本。 |
| `build_ik_candidate_pool(...)` | 对 dense 计划扩展确定性备用候选；非 dense 原样返回。 |
| `reindex_samples(samples)` | 候选替换后把输出 index 重新编号为连续整数。 |
| `depth_distribution_summary(samples, args)` | 统计实际 min/max/mean 和 1 mm 分箱。 |
| `spatial_coverage_summary(samples)` | 按 region 统计独立 X/Y 锚点数、最小间距和 X/Y 跨度。 |
| `csv_depth_limit_summary(samples, rows)` | 统计低于/高于 CSV 推荐深度的样本、类别/区域和最大超限量。 |
| `apply_first_contact_test(samples, args)` | 把唯一样本改成最小压深和零倾角的首点验证。 |
| `board_surface_correction_mm(sample, args)` | 按优先级返回外部高度标定、运行时 datum 或人工 offset；倾角与某些标定组合会被拒绝。 |

### 17.3 路线和预览（约 2128-2749 行）

| 函数 | 职责、返回值与重要副作用 |
|---|---|
| `make_route(...)` | 从样本和 fixture 生成 contact/approach/site-high/outbound/return；应用板高与 reference correction。 |
| `maximum_below_nominal_contact_mm(args, depth)` | 计算样本最终允许低于名义面的硬上限。 |
| `maximum_capture_tcp(route, args, depth)` | 生成视觉搜索与最终压入可能到达的最深 TCP，供计划/IK 使用。 |
| `route_ik_targets(route, args, depth)` | 生成整批 IK 要检查的五个连续目标。 |
| `reference_route(fixture, dock_design, args)` | 为可选 reference pad 生成 approach/outbound/return。 |
| `route_records(route)` | 把 `(label, pose)` 转成可 JSON 序列化记录。 |
| `write_plan_csv(...)` | 写样本元数据和四组 CR3 TCP；无 fixture 时 TCP 列为空。 |
| `_cached_preview_mesh_arrays(...)` | 用修改时间/大小作为缓存失效条件加载并抽稀 STL，仅供可视化。 |
| `load_preview_mesh_arrays(path, face_limit)` | 检查 face limit 并调用缓存加载器。 |
| `write_plan_preview(...)` | 写 tile-local 采样点、STL、类别和独立锚点的 Plotly HTML。 |
| `base_to_tile_local(fixture, xyz)` | 对位置执行 fixture 反变换，主要用于预览与标高记录。 |
| `write_ik_candidate_preview(...)` | 显示请求点、备用候选和每区域代表性路线。 |
| `write_motion_route_preview(...)` | 显示完整 TCP 运动包络；蓝色 transit、红色最深搜索界、虚线返回、紫色触头 footprint。只预览前六个样本。 |

### 17.4 图像接触与报告（约 2750-3414 行）

| 函数 | 职责、返回值与重要副作用 |
|---|---|
| `prepare_run_dir(args)` | 创建独占的新运行目录；已存在会失败，避免覆盖。 |
| `discard_intermediate_capture(output_dir, record)` | 安全删除 baseline/search 等中间 raw、预处理和 motion 图，并清理记录中的路径。 |
| `prepare_site_baseline(...)` | 拍 baseline/noise probes，计算 mean/P95 动态阈值。 |
| `bounded_search_depths(max_depth, step)` | 生成不越界且一定包含精确终点的深度序列。 |
| `refine_visual_contact_bracket(...)` | 只在已探索粗区间内做释放确认和细步进；不会扩大深度边界。 |
| `search_visual_contact(...)` | 完整视觉接触状态机：baseline、步进、同位确认、可选 refinement、最终压入和 capture。 |
| `execute_route(robot, route, prefix, args)` | 顺序调用 `move_and_verify()` 执行一组已命名 waypoint。 |
| `write_collection_csv(path, records)` | 把 JSON 中每个样本的关键字段、图像、统计和 TCP 扁平化成 CSV。 |
| `build_report(path, payload, max_cards)` | 生成 raw 与模型输入并排的 HTML；只限制页面卡片数，不删 CSV/JSON 数据。 |
| `write_run_readme(...)` | 在每个运行目录写本次参数、深度策略、路线和安全契约摘要。 |

### 17.5 IK、恢复与采集（约 3415-4708 行）

| 函数 | 职责、返回值与重要副作用 |
|---|---|
| `check_ik_target(...)` | 用 near-joint 查询一个目标；区分无解、分支失败和通信失败；可记录无提示诊断。无运动。 |
| `check_ik_sequence(...)` | 按路线顺序传播每一步 IK 解；上游失败后把后续目标标记为未检查。 |
| `preflight_sample_route(...)` | 检查一个候选从 site-high 到最深点再返回的完整分支。 |
| `select_ik_reachable_samples(...)` | 按 region 目标数从候选池选择可达点，生成详细筛选/性能报告。无运动。 |
| `skip_full_route_preflight(...)` | 默认快速路径：保留原样本并明确写出“整批预检跳过”，不影响真实运动前的即时 IK。 |
| `run_ik_preflight(...)` | 连接 CR3、要求当前在托座、检查 route 并写 IK-filtered plan；不发运动。 |
| `run_reseat_dock(...)` | 只允许从 dock/dock-exit/dock-high 附近回托；其他起点拒绝。 |
| `run_recover_reference_to_dock(...)` | 验证当前在 reference 搜索轴包络内，再走已知高位路线回托。 |
| `low_pose_recovery_route(...)` | 验证低位起点范围，生成“先垂直抬升、后横移”的恢复路线和解释记录。 |
| `run_recover_low_pose_to_dock(...)` | 读取实时位姿、生成路线、整条 IK 预检；有 `--execute` 才执行并验证最终落座。 |
| `run_collection(...)` | 正式采集总状态机：设备连接、托座门、可选 reference、IK 筛选、逐点采集、回托和报告。异常时不自动恢复。 |

### 17.6 运行时标高与主入口（约 4709-5271 行）

| 函数 | 职责、返回值与重要副作用 |
|---|---|
| `runtime_height_measurements_from_collection(...)` | 把每次 contact/no-contact bracket 从 CR3 base 转成 tile-local 测量行。 |
| `run_runtime_height_calibration(...)` | 创建 12 点计划、调用正式采集、构建并质量验收 datum；只有全部门槛通过后才写入正式 datum 路径。 |
| `run_verify_dock_tactile_reference(...)` | 连接 CR3/相机，要求 TCP 已落座，只做横档图像核验，不运动。 |
| `run_capture_camera_only(...)` | 不连接 CR3，用正式多帧+预处理路径保存一张 TacTip 图和 JSON。 |
| `run(args)` | 所有模式的总调度、计划生成、绑定检查、预览输出和执行授权。 |
| `main()` | 捕获最外层异常，向 stderr 输出统一 `COVERAGE_BOARD_SAMPLER_FAILED`，以 1 退出。 |

## 18. 输出目录与文件含义

### 18.1 计划阶段总会生成

| 文件 | 内容 |
|---|---|
| `sampling_plan.json` | 完整不可变计划、输入哈希、配置、样本列表和统计 |
| `sampling_plan.csv` | 便于人工检查的扁平计划和 TCP |
| `README.md` | 本次运行参数和安全契约 |
| `planned_sampling_points_3d.html` | tile-local 点位预览 |
| `full_tcp_motion_safety_preview.html` | 有真实 fixture 时的完整 TCP 包络 |
| `ik_candidate_pool_preview.html` | 仅整批 IK 模式生成 |

### 18.2 正式采集增加

| 文件/目录 | 内容 |
|---|---|
| `collection.json` | 最完整的状态机记录；每一步 motion、threshold、frame、TCP 和错误都在这里 |
| `samples.csv` | 最终样本摘要，便于训练/统计读取 |
| `collection_report.html` | raw 与 GAN 输入图的可视化卡片 |
| `ik_route_filter.json` | 整批 IK 的筛选结果，或明确记录默认跳过 |
| `ik_filtered_sampling_plan.json/.csv` | 最终进入执行循环的样本 |
| `runtime_adjusted_sampling_plan.csv` | 应用 reference correction/height datum 后的实际计划 |
| `frames/` | 原始 TacTip 图，具体目录名由拍摄模块管理 |
| `tactip_preprocessed/` | gray、ring-suppressed、native model input、256x256、ROI、overlay |
| `analysis/` | marker motion 可视化；中间搜索图默认可能被清理 |

### 18.3 为什么先看 `collection.json`

CSV 只保留常用字段。检查某个点为什么未命中时，应在 JSON 中查看：

- `threshold.mean/p95`；
- 每一帧的 `marker_motion.mean/p95` 与 `hit`；
- 每步 `target_tcp`、`actual_tcp` 和误差；
- `last_actual_relative_to_nominal_mm`；
- `first_contact_bracket`；
- `status` 和 `reason`。

## 19. 常用命令模板

以下命令是结构示例。正式执行前仍应检查当前 tile、输出目录、实物安装、相机 source 和 profile。

### 19.1 只生成 2,000 点计划与轨迹

```bash
.venv/bin/python tools/auto_cr3_coverage_board_sampler.py \
  --tile tile_ne \
  --samples-per-tile 2000 \
  --continuous-board-transit
```

没有 `--execute`，因此不会连接或移动 CR3。

### 19.2 横档托座重新标定

```bash
.venv/bin/python tools/auto_cr3_coverage_board_sampler.py \
  --tile tile_ne \
  --calibrate-height-from-rest-stop \
  --camera-source 0
```

这个模式读取 TCP 和拍图，但不发送运动。

### 19.3 只验证当前是否正确归位

```bash
.venv/bin/python tools/auto_cr3_coverage_board_sampler.py \
  --tile tile_ne \
  --verify-dock-tactile-reference-only \
  --camera-source 0
```

### 19.4 单点低风险首接触

```bash
.venv/bin/python tools/auto_cr3_coverage_board_sampler.py \
  --tile tile_ne \
  --site R07_S05 \
  --profile quick \
  --max-samples 1 \
  --first-contact-test \
  --min-post-contact-depth-mm 1 \
  --max-post-contact-depth-mm 1 \
  --camera-source 0 \
  --execute \
  --yes-i-confirm-cr3-is-safe
```

### 19.5 正式 2,000 点连续采样

```bash
.venv/bin/python tools/auto_cr3_coverage_board_sampler.py \
  --tile tile_ne \
  --samples-per-tile 2000 \
  --min-post-contact-depth-mm 1 \
  --max-post-contact-depth-mm 10 \
  --continuous-board-transit \
  --continue-on-no-contact \
  --camera-source 0 \
  --speed 5 \
  --execute \
  --yes-i-confirm-cr3-is-safe
```

### 19.6 从安全停止的旧运行续采

```bash
.venv/bin/python tools/auto_cr3_coverage_board_sampler.py \
  --tile tile_ne \
  --samples-per-tile 2000 \
  --min-post-contact-depth-mm 1 \
  --max-post-contact-depth-mm 10 \
  --continuous-board-transit \
  --resume-from-run /ABSOLUTE/PATH/TO/OLD_RUN \
  --camera-source 0 \
  --execute \
  --yes-i-confirm-cr3-is-safe
```

必须与旧运行使用同样的 seed、布局、深度、倾角和过滤参数。

## 20. 常见问题定位

### 20.1 `not seated at fixture datum`

含义：当前 Tool TCP 不在保存托座容差内，也不满足短距离纯竖直回落条件。

检查：Tool 是否为 2、User 是否为 0、是否真的装入同一托座、profile 是否属于当前 tile、当前姿态是否变化。

### 20.2 TCP 通过但横档触觉图失败

含义：机械位姿看似相同，但 TacTip 没有以标定时的方式接触横档，或者相机/照明/marker 检测发生明显变化。

优先检查实物是否完全落座、镜头/LED 是否改变、相机 source 是否正确。不要直接把 `--skip-dock-tactile-reference-check` 当作常规修复。

### 20.3 `no CR3 inverse-kinematics solution; MovL was not sent`

含义：当前关节分支到目标位姿没有控制器认可的 IK，命令没有发送。可能是工作空间边界，也可能是 near-joint 分支不兼容。

使用 `--ik-preflight-only --ik-diagnose-failures` 可以区分；正式 2,000 点运行可选择 `--preflight-all-routes` 让备用候选替换不可达点。

### 20.4 到名义面仍没有接触

脚本会继续搜索，但只到 `contact_search_margin_mm` 允许的板高误差。原因可能包括 fixture/profile 不匹配、板子没有贴合安装、Tool TCP 错误、当前点解析高度错误或视觉 detector 未命中。

不应无上限扩大深度。先检查 `collection.json` 中实际 TCP、名义偏差和 marker motion，再决定是修正全局高度 datum 还是局部几何。

### 20.5 有明显形变但检测未命中

检查同一点的：

```text
threshold.mean / threshold.p95
frame.marker_motion.mean / frame.marker_motion.p95
preprocess_attempts
preprocess_rejections_before_accept
```

两个统计必须同时过阈值。反光导致 marker 图不稳定时，动态噪声阈值也可能被抬高。

### 20.6 为什么运行中间图不见了

这是默认磁盘策略，不是拍摄失败。增加 `--save-search-frames` 后 baseline/noise/search/confirm 图才会全部保留。

### 20.7 当前版本执行 `--help` 报 `%` 格式错误

当前源码的模块说明和一个参数帮助字符串中含有未转义的字面量 `1%`。`argparse` 在生成帮助页时会把 `%` 当作格式符，因此当前版本单独执行 `--help` 会出现 `unsupported format character`。这不影响正常参数解析或采样逻辑，但后续维护时应把帮助文本中的 `%` 写成 `%%`；本文档任务没有修改采样脚本本身。

## 21. 脚本能保证什么、不能保证什么

### 能保证的代码约束

- 没有双重执行确认时不发送普通 CR3 运动。
- 目标位姿必须是有限 6D 数值。
- 默认每个 `MovL` 前必须有当前分支 IK 解。
- 每次运动后必须收到真实关节/TCP 反馈并通过误差门槛。
- 起始托座 TCP 与横档触觉图都要匹配。
- 视觉搜索和最终压入受每样本硬深度上限限制。
- 横向 transit 在规划的安全高度发生。
- 续采必须重现完全相同的计划和硬件绑定。

### 不能单靠该脚本保证的事情

- `site_high` 与机械臂整条连杆在真实环境中的全身碰撞自由；当前主要约束 TCP 路线和工作空间 IK。
- 板外临时物体、电缆、夹具或操作员不会进入路线。
- 错误的 Tool(2) 几何仍能代表真实 TacTip apex。
- CAD、打印件和装配完全一致。
- marker 视觉阈值等同于严格零力接触。
- 深压不会超过具体材料和传感器的力学极限；脚本只执行配置的几何上限。

因此 HTML 轨迹、首点低压测试和现场急停仍是正式实验的一部分，不应因为自动化存在而省略。

## 22. 建议的阅读顺序

如果要修改代码，建议按下面顺序阅读：

1. `BoardSample` 与 `FixtureTransform`：先理解数据和坐标。
2. `build_dense_samples()`：理解采什么点。
3. `make_route()`：理解每个点如何变成 TCP 路线。
4. `search_visual_contact()`：理解如何判断接触和控制深度。
5. 外部 `move_and_verify()`：理解每一步真实运动的保护。
6. `run_collection()`：理解所有模块如何串起来。
7. `run()` 与 `parse_args()`：最后理解各模式和参数如何进入主流程。

这样比从 5,271 行文件顶部逐行读到底更容易建立完整心智模型。

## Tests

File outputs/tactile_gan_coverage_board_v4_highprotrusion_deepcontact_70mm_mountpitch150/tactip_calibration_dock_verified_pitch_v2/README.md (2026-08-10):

# Verified TacTip Calibration Dock v2 (150 mm)

This optional rigid dock is matched to the public v4 board variant whose south mounting-hole pair is exactly 150 mm apart.

## Included STL

Use `v4_tactip_calibration_dock_v2_exact_150.stl` only when the two south board-hole centres measure **150 mm**. The former 156 mm and dual-pitch development variants are intentionally not part of this repository.

## Mechanical check before collecting

1. Put the tile with its tactile surface facing up.
2. Put the dock on the south edge: the straight rear rail must touch the tile's straight edge.
3. Slide the board into the continuous C-shaped rail: its underside sits on the lower lip and its south edge reaches the hard stop.
4. Insert both M6 screws without force. Both must drop through the dock and into the board together.
5. Tighten both screws. The dock must not translate or yaw by hand.
6. Only then seat the TacTip and record a **new** Tool(2) fixture profile.

The board's 6.0 mm holes remain unchanged. The dock's 6.6 mm holes are deliberate M6 clearance, not an error.

Key files:

- `v4_tactip_calibration_dock_v2_exact_150.stl`
- `v4_tactip_calibration_dock_v2_exact_150_design.json`
- `v4_tactip_calibration_dock_v2_hole_alignment.png`
- `v4_tactip_calibration_dock_v2_clip_section.png`

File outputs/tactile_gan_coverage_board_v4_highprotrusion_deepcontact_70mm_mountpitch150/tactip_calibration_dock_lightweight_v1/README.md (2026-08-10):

# Lightweight TacTip calibration dock for v4 150 mm board

This one-piece dock is for the non-destructive v4 mounting-hole variant. It shares the two south-edge M6 tile holes at local `(-75,-75)` and `(75,-75)` mm, so the mounting pitch is exactly `150.0 mm`. The board must remain bolted flat through all four of its own M6 holes; the dock's two feet rest on that same table.

## Installation

1. Print the dock with its two feet down.
2. Bolt a v4 170 mm tile to the table. Keep the dock at tile-local `-Y`.
3. Loosen the south pair of board screws, slide the dock U-slots in from local `-Y`, and retighten the two M6 screws.
4. Seat the rigid TacTip flange in the 50.8 mm guide. The compliant tip remains clear through the 44 mm opening.
5. Record Tool(2) while seated. This is the repeatable rest datum for automatic collection.

The `*_design.json` file records the complete local geometry, including the nominal seated Tool(2) TCP and reference-pad height.

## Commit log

2026-08-10 Add CR3 coverage-board sampling tools
    Add planning, IK preflight, contact detection, camera preprocessing, hardware generation, and collection tools.
2026-08-10 Add GAN coverage board metadata
    Add board documentation, URDF, manifest, sampling sites, and assembly preview.
    [tactile_gan_coverage_board_340mm.urdf, tactile_gan_coverage_board_340mm_sampling_sites.csv]
2026-08-10 Add NE GAN coverage-board tile
2026-08-10 Add NW GAN coverage-board tile
2026-08-10 Add SE GAN coverage-board tile
2026-08-10 Add SW GAN coverage-board tile
2026-08-10 Add lightweight TacTip calibration dock
    Add the default material-efficient dock STL, design metadata, installation layout, and preview.
    [v4_150mm_tactip_calibration_dock_lightweight.stl]
2026-08-10 Add exact-150 TacTip calibration dock
    Add the optional rigid exact-150 mm mounting-pitch dock STL, design metadata, and alignment diagrams.
    [v4_tactip_calibration_dock_v2_exact_150.stl]
2026-08-21 Replace TacTip preprocessing with Hough color filter
    Use grayscale Hough circle detection plus 2B-G-R chromatic rejection, require all 331 marker components, preserve raw captures, and share the same implementation between batch and live samplers.
